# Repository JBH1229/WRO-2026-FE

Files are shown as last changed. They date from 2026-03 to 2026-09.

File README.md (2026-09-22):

# WRO Future Engineers 2026
Our repository for the 2026 World Robot Olympiad: in the category Future Engineers

# Team Costco Hotdog
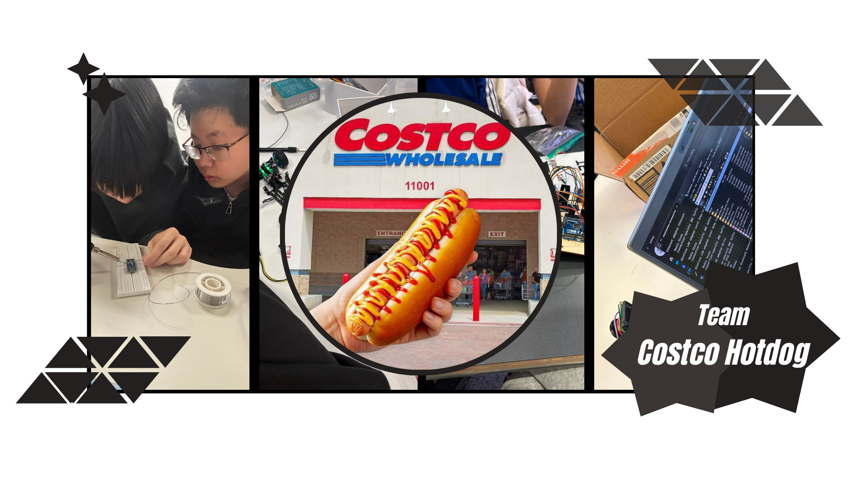
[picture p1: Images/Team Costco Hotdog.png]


## Explorer Robotics





## Table of Contents
* [The Team](#team-members)
* [Engineering Journal](#engineering-journal)
* [The Challenge](#the-future-engineers-challenge)
* [The Robot](#robot)
  * [Overview](#overview) 
  * [First Design](#first-design)
  * [Design Decisions](#design-decisions)
  * [Final Design](#final-design)
* [Prices](#price-of-the-components)
* [Power](#power)
  * [Power budget](#power-budget)
  * [Regulator & BEC Efficiency Losses](#regulator-and-bec-efficiency-losses)
* [Systems](#systems)
  * [Mechanical System](#mechanical-system)
      * [Motor](#motor)
      * [Servo Motor](#servo-motor)
      * [Wheels](#wheels)
  * [Electrical & Sensor System](#electrical-and-sensor-systems)
    * [Regulator](#voltage-regulation)
    * [Circuit Diagram](#circuit-diagram)
* [Software](#software)
* [Testing](#testing)
  * [Performance Videos](#performance-videos)
    * [Open challenge](#open-challenge-video)
    * [Obstacle Challenge](#obstacle-challenge-video)

# Team Members

### Jonathan Huang
**Age:** 15

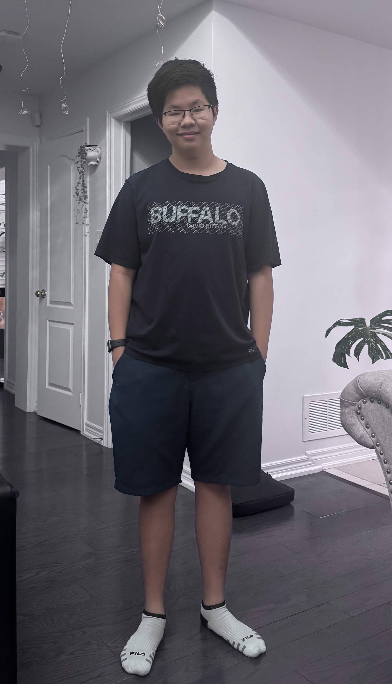
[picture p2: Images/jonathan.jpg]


**Introduction:**
Hi, my name is Jonathan and I'm from Canada, this is my fifth WRO season. I am interested in airplanes, and enjoy learning about how they work in my free time. Besides that, I enjoy playing video games with my friends. I am currently attending Notre Dame CSS.

### Walter Wu
**Age:** 15

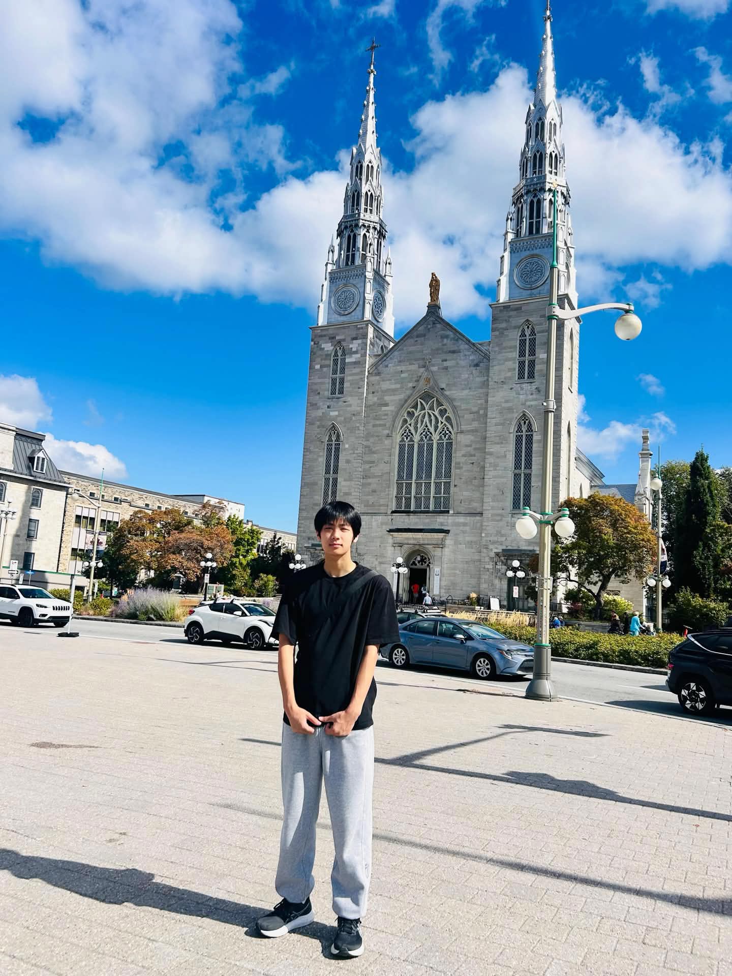
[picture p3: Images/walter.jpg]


**Introduction:**
Hi, my name is Walter and I'm also from Canada, this is my third WRO season;  I have many interests, such as sports like volleyball, and hobbies ranging from drawing and video games to cooking. I am currently attending All Saints CSS and am enrolled in their Arts & Media Program.

# Our Coach
<table>
  <tr>
    <td width="50%" style="text-align: left;">
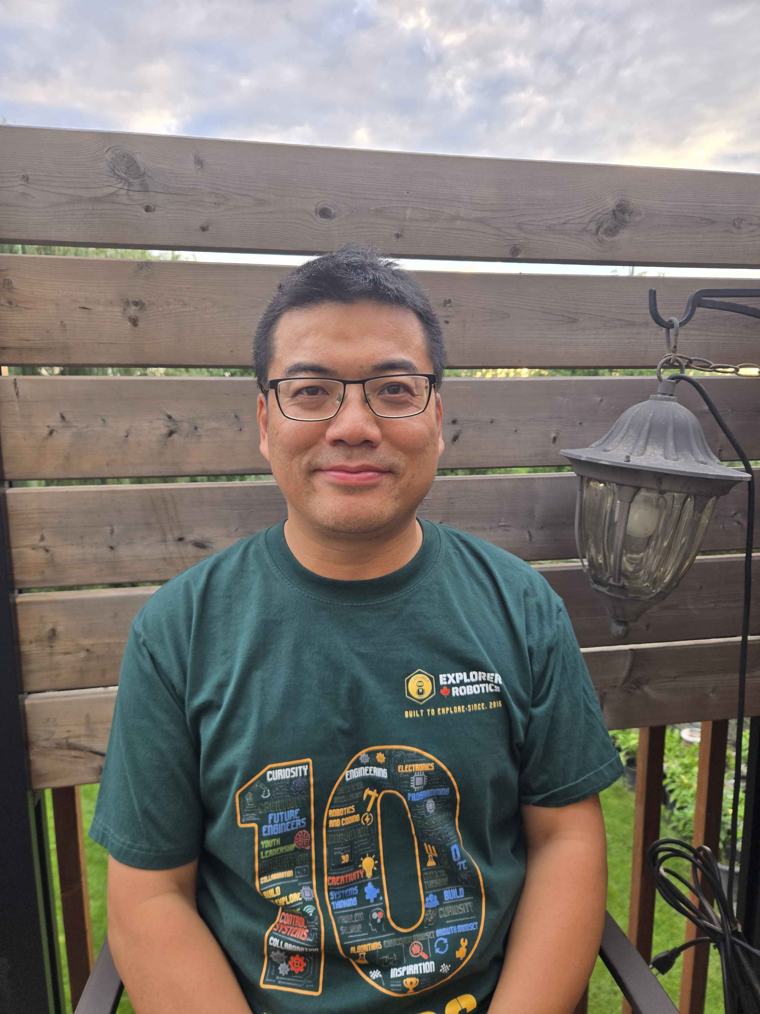
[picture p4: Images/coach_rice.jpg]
       
    </td>
    <td width="50%" style="text-align: left; vertical-align: top;">
      <h3>Accolades:</h3>
      <ul>
        <li>Head coach of Robotics Competitions including FLL (First LEGO League) Tournament and WRO (World Robotics Olympiad). Led teams in winning multiple national, international robotics and programming awards.</li>
        <li>Over 20 years of IT industry experience as software engineer working internationally.</li>
        <li>MSc in Electrical & Computer Engineering from University of Alberta.</li>
        <li>BSc in Mathematics from Peking University.</li>
      </ul>
    </td>
  </tr>
</table>

# Engineering Journal
Here is the link to our [Engineering Journal google document](https://docs.google.com/document/d/1yOxLSaLgVKeupWdl-JZPw-9g1dGKT5EjSAjHi6xOg-0/edit?tab=t.0)

# The Future Engineers Challenge
### Open Challenge

The **Open Challenge** tests our robot's ability to drive autonomously around the track. The robot must complete three laps while adapting to different track layouts, starting positions, and driving directions. The goal is to create a fast and reliable self-driving vehicle that can navigate the track and stop whenever needed without human control.

### Obstacle Challenge

The **Obstacle Challenge** adds red and green traffic signs to the track as well as a parking area. Teams have an option to start and end within the parking area to accumulate more points. While completing three laps, the robot must identify the traffic signs and choose the correct side of the lane to pass on. After finishing the laps, the robot will optionally find the parking area and successfully parallel park.
### Documentation

The **Documentation** focuses on explaining how our robot was designed and developed. Our GitHub repository includes information about the robot's hardware, software, sensors, power system, and driving strategies. It also contains photos, videos, source code, and updates showing our engineering process and improvements throughout the project.

Learn more about the challenges WRO has to offer and the rules accordingly [here](https://wro-association.org/competition/2026-season/) and [here](https://wro-association.org/competition/2026-season/)

# Robot
## Overview

| Dimension | Measurement |
|---|---|
| Length | 21 cm |
| Width | 10 cm |
| Height | 24.5 cm |
| Wheelbase | 10.2 cm |
| Ground Clearance | 3mm |
| Weight | 567g |

## Drive Configuration

The robot uses a **RWD** drivetrain powered by a **Furitek Micro Komodo 1212 brushless motor** and controlled by a **Furitek Lizard Pro ESC**.

### Drive Components

| Component | Specification |
|---|---|
| Motor | Furitek Micro Komodo 1212 |
| Motor Type | Brushless DC |
| ESC | Furitek Lizard Pro |
| Drive Type | RWD |
| Driven Wheels | 1/28 RC drift car wheels |

The motor receives speed commands from the control system through the ESC which decodes PWM messages from the Pi. The drivetrain converts the motor's rotation into forward and reverse movement.

## Steering Configuration

The robot uses **servo-based steering** to control its direction.

### Steering Components

| Component | Specification |
|---|---|
| Steering Servo | HiTec HS-5055MG Micro Servo |
| Control Signal | PWM |
| Maximum Steering Angle | 45° |
| Steering Type | Ball joint |

The steering servo is connected to the front steering mechanism through a mechanical linkage connecting first to a ball joint to drive the steering system.. The controller adjusts the servo position using PWM signals to change the robot's steering angle.

## Main Components

| Component | Purpose |
|---|---|
| Raspberry Pi 5 | Main computer and processing |
| Arduino Nano | Low level commands and processing IMU data |
| Furitek Micro Komodo 1212 | Drives the robot |
| Furitek Lizard Pro ESC | Controls the drive motor |
| Steering Servo | Controls steering |
| D500 LiDAR | Distance measurement |
| Raspberry Pi Camera | Vision and object detection |
| 5 V Regulator | Powers 5 V electronics |
| 11.1 V LiPo Battery | Main power source |
| BMI270 IMU | Used for its gyro sensor |

## Sensors

The robot uses multiple sensors to perceive its surroundings and determine its position on the course.

| Sensor | Purpose | 
|---|---|
| Raspberry Pi Camera | Detects and identifies objects/colours |
| D500 LiDAR | Measures distance to surrounding objects/walls |
| IMU | The gyro sensor inside calculates the robot's heading |

Sensor data is processed by the robot's control software and used to make driving and steering decisions.

### PHOTO OF SENSORS ON ROBOT ###
| *Pi Camera* | *2D LiDAR* | *IMU* |
| :--: | :--: | :--: |
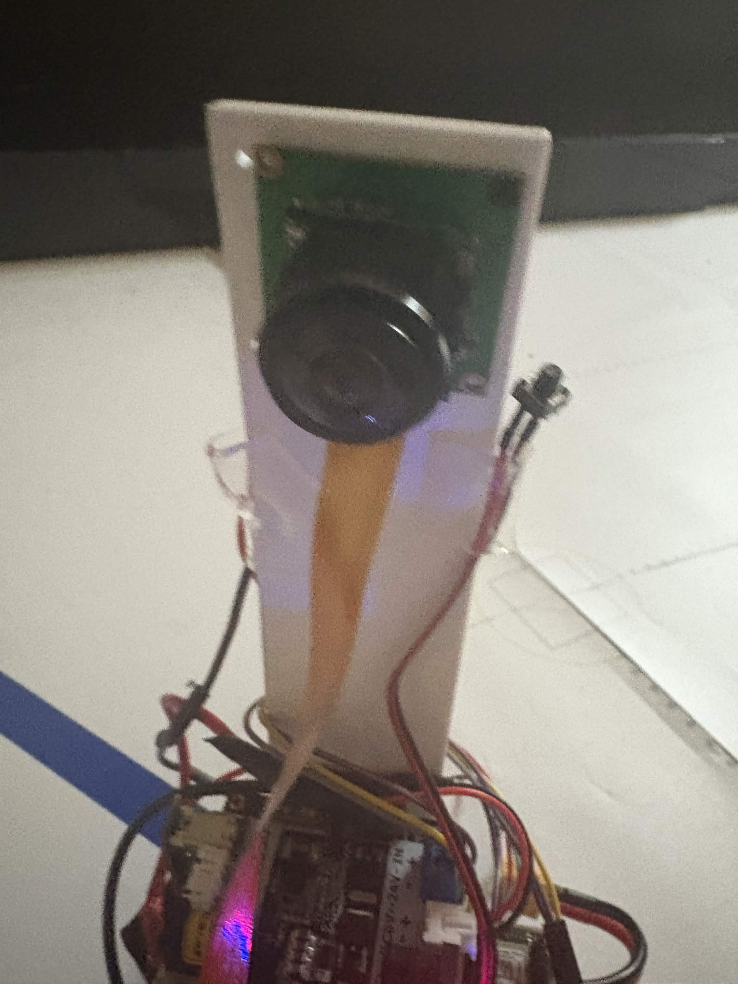
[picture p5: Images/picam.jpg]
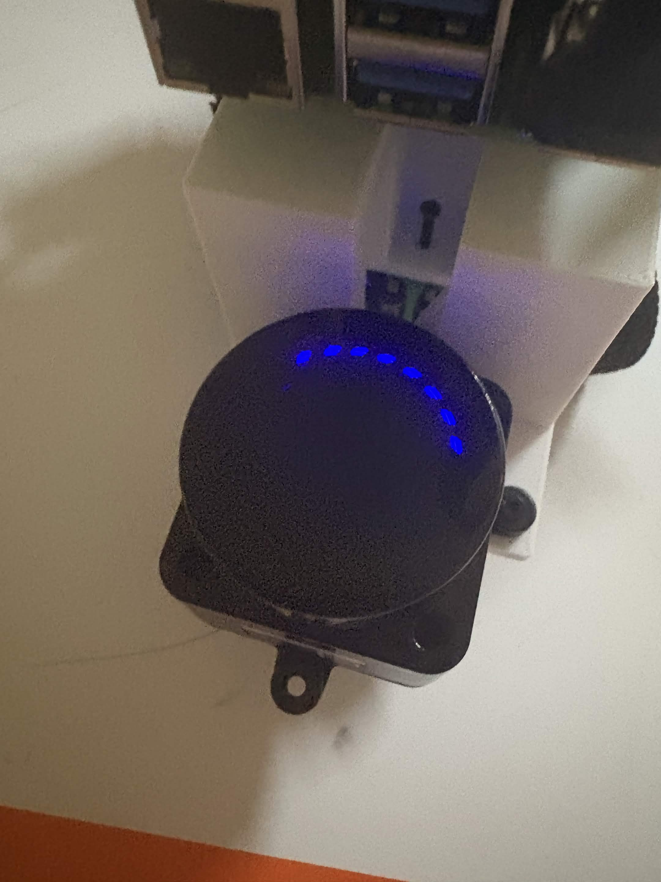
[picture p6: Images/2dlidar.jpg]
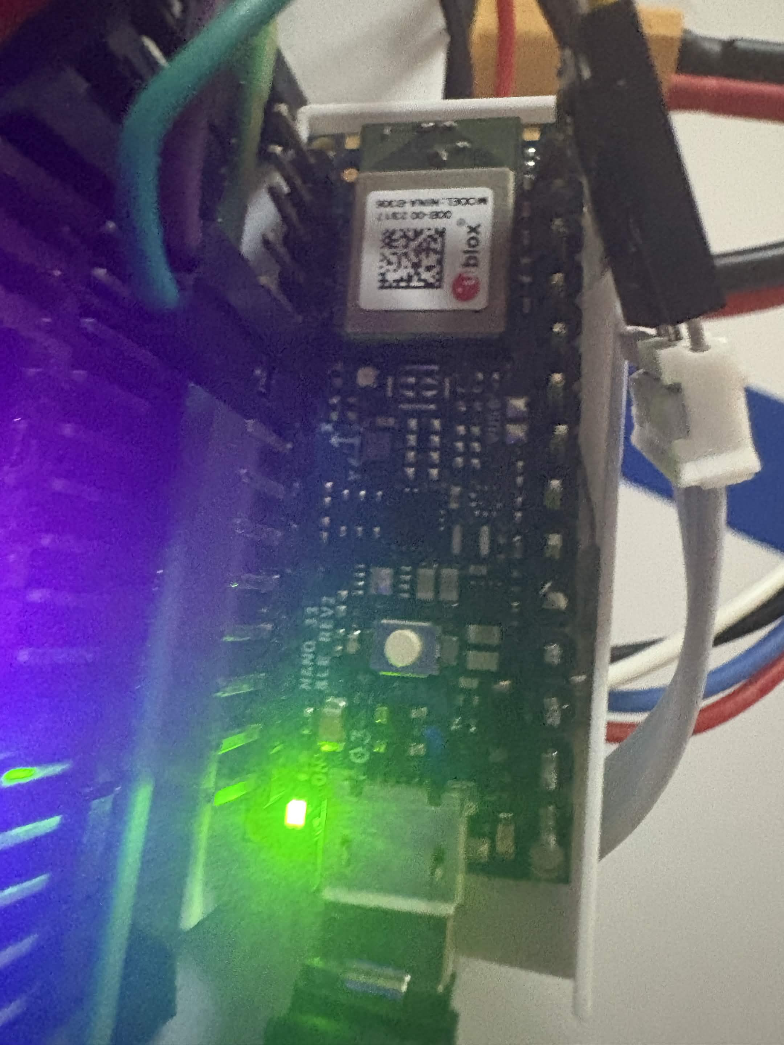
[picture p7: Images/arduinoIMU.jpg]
|  |  |  |

## Computer / Controller

The main computer is a **Raspberry Pi 5**, which processes sensor data and runs the robot's control software.

An **Arduino Nano** is used for low-level control of the robot's steering servo and motor ESC, as well as processing IMU data to track the robot's heading.

### Computer/Controller Components

| Component | Function |
|---|---|
| Raspberry Pi 5 | Main processing, computer vision, navigation and decision-making |
| Arduino Nano | Low level commands and IMU interpretation |
| Motor ESC | Motor control |
| Steering Servo | Steering control |

The Raspberry Pi receives information from the sensors, processes the data, and sends control commands to the Arduino, which then controls the drive and steering systems.

## Battery

The robot is powered by an **11.1 V 2200 mAh 3-cell LiPo battery**.

| Specification | Value |
|---|---|
| Battery Type | LiPo |
| Cells | 3S |
| Nominal Voltage | 11.1 V |
| Capacity | 2200 mAh |
| Average Current | ~3.5 A |
| Peak Current | ~15 A |
| Average Power | ~38 W |
| Estimated Runtime | 40–60 minutes |

The battery directly powers the drive system and provides power to the electronics through the appropriate voltage regulation.

## How It Works

The robot operates using a combination of **computer vision, LiDAR distance sensing, and autonomous control**.

The **Raspberry Pi 5** collects information from the camera and LiDAR and processes this data using the robot's control software. The camera is used to identify relevant objects and course features, while the LiDAR provides distance measurements to help the robot understand its surroundings.

Based on the sensor data, the software determines the appropriate **steering angle and driving speed**. Steering commands are sent to the steering servo, while drive commands are sent to the motor through the **Furitek Lizard Pro ESC**.

The robot continuously repeats this process:

**Sense → Process → Decide → Drive/Steer → Sense**

## First design
These are a couple pictures of the first variation of our robot
| *Side* | *Camera Detached* |
| :--: | :--: |
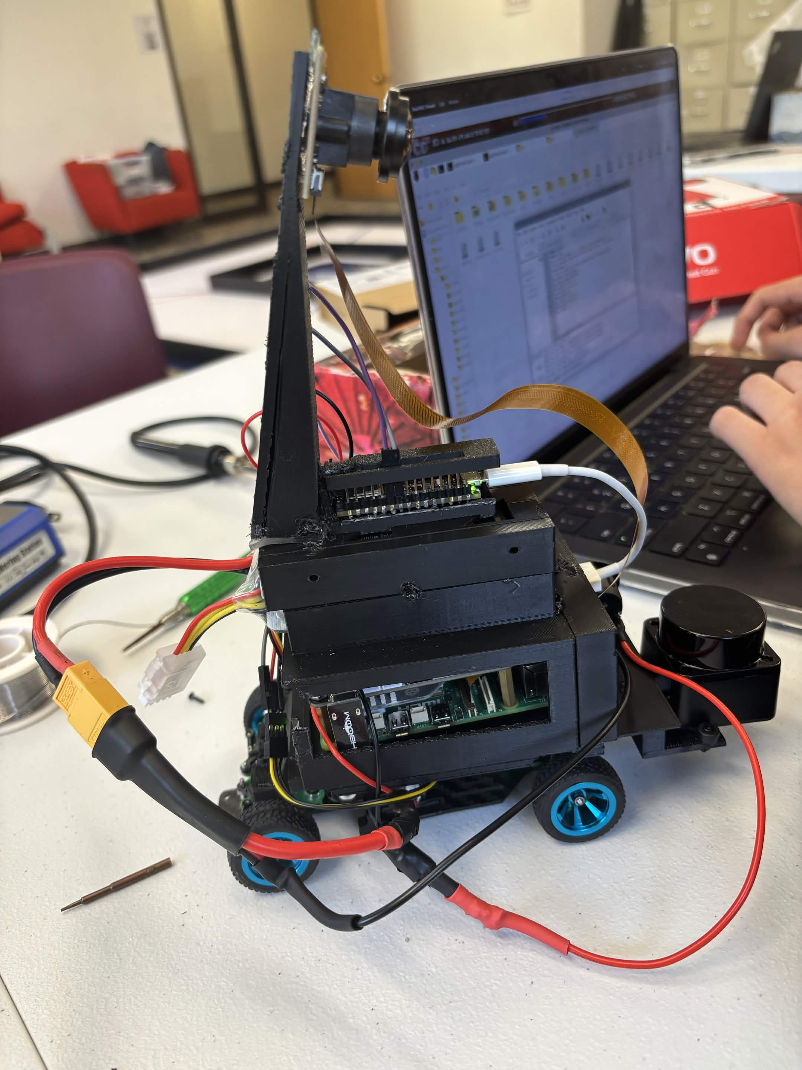
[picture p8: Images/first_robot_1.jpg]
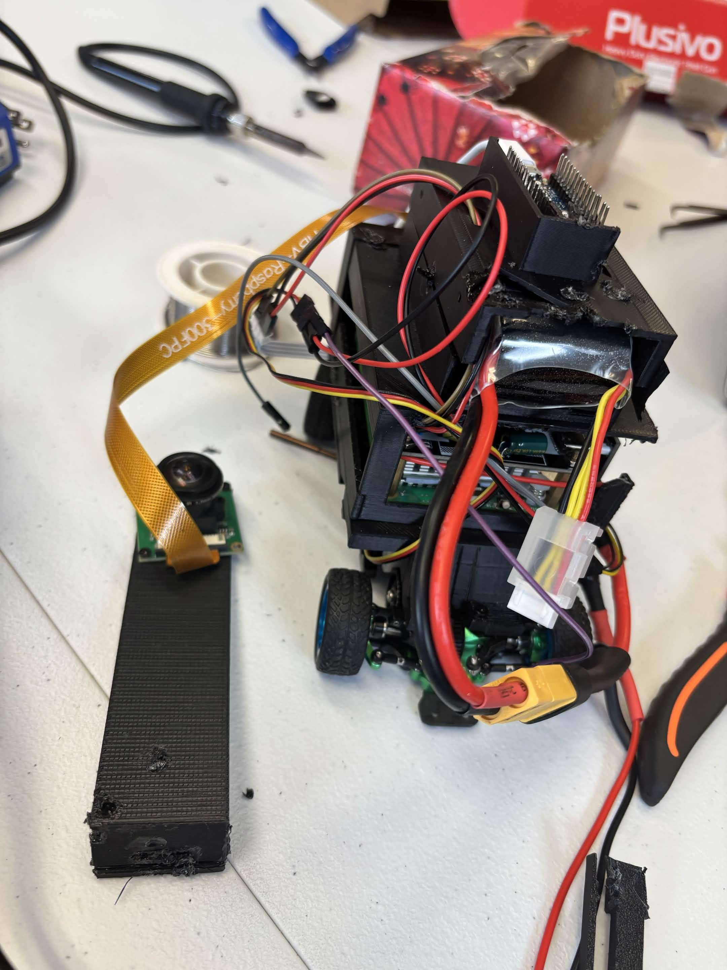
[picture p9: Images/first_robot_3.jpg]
|  |  | 

### Early CAD designs
The following are photos of early iterations for the chassis and camera stand
| *Camera Stand* | *Chassis* |
| :--: | :--: |
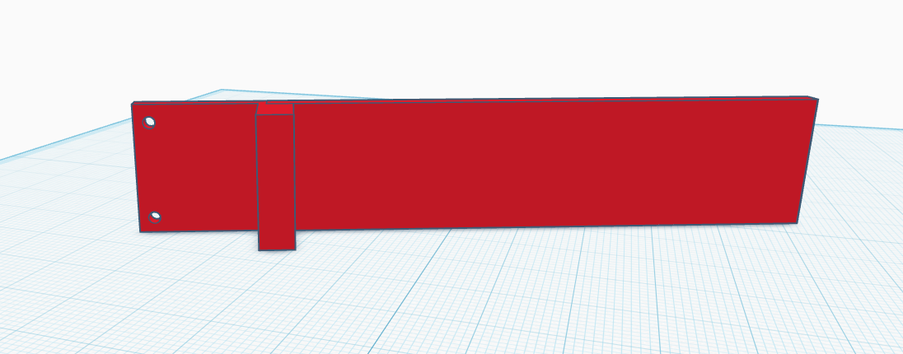
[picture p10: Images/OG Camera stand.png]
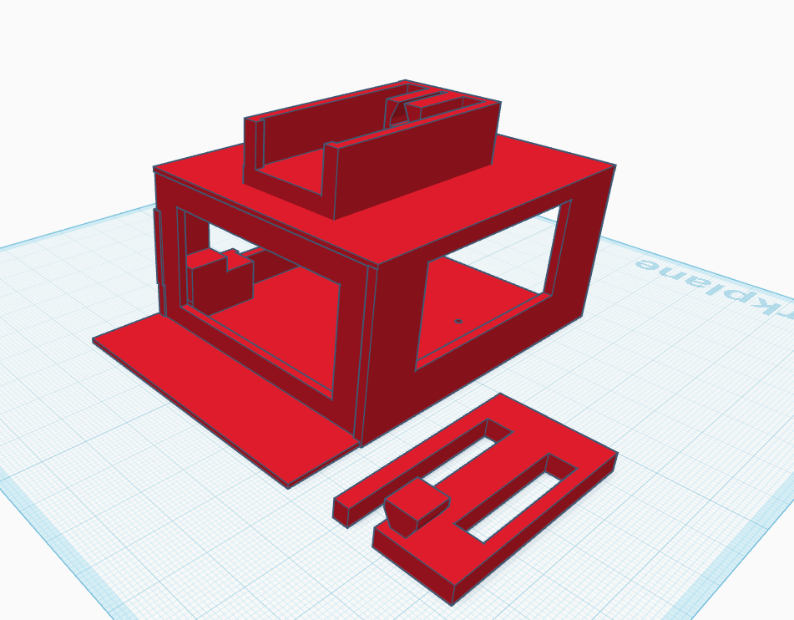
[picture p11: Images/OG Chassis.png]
|  |  | 

## Design Decisions
A lot of the design decisions were based on the information and research done on previous robots from both team members and our club.
| Challenge | Decision | Reasoning |
|---|---|---|
| Drive system | Furitek Micro Komodo 1212 BLDC motor with a Furitek Lizard Pro ESC | Provides enough torque and speed for the robot while remaining compact and efficient. The brushless motor also provides reliable and precise control. |
| Size | 1/24 - 1/28 scale | A compact design makes the robot easier to maneuver, turn, and navigate through tight sections of the course while staying within the competition size limits. |
| Battery | 11.1 V 2200 mAh 3-cell LiPo battery | Provides enough voltage for the drive system and sufficient capacity for the robot to operate throughout a run while keeping the overall weight low. |
| Controller | Raspberry Pi 5 with an Arduino Nano | The Raspberry Pi 5 handles sensor processing, decision-making, and higher-level control, while the Arduino Nano handles real-time communication with the drive and steering systems. |
| Sensors | D500 LiDAR, Raspberry Pi Camera, and BMI270/BMM150 IMU | LiDAR provides distance measurements for navigation and wall detection, the camera provides visual information, and the IMU provides orientation and motion data for more accurate movement and turning. |

A **more detailed breakdown** of our decisions can be found in our [Engineering Journal](https://docs.google.com/document/d/1yOxLSaLgVKeupWdl-JZPw-9g1dGKT5EjSAjHi6xOg-0/edit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)

## Wheelbase
The distance for our wheelbase was chosen to be shorter to help with agility, nmainly so our robot could take shaper and more concise turns if needed to. This especially helps with the obstacle challenge and proved to be beneficial during the suprise rule for nationals, where we had to navigate around an extra, yellow coloured, pillar. When you look at real life examples of cars with long wheelbases, such as F1 cars, it is noted that F1 cars also have a trouble with turning. One reason behind this is that having a longer wheelbase directly increases the turn radius of your car. A larger turn radius means wider turns and completely contrasts the goal for our autonomous robots.

Learn about our robots turn radius in our engineering journal on page 12 [Engineering Journal](https://docs.google.com/document/d/1yOxLSaLgVKeupWdl-JZPw-9g1dGKT5EjSAjHi6xOg-0/edit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)

## Final Design
Here are photos of our final design|

| *Front* | *Back* |
| :--: | :--: |
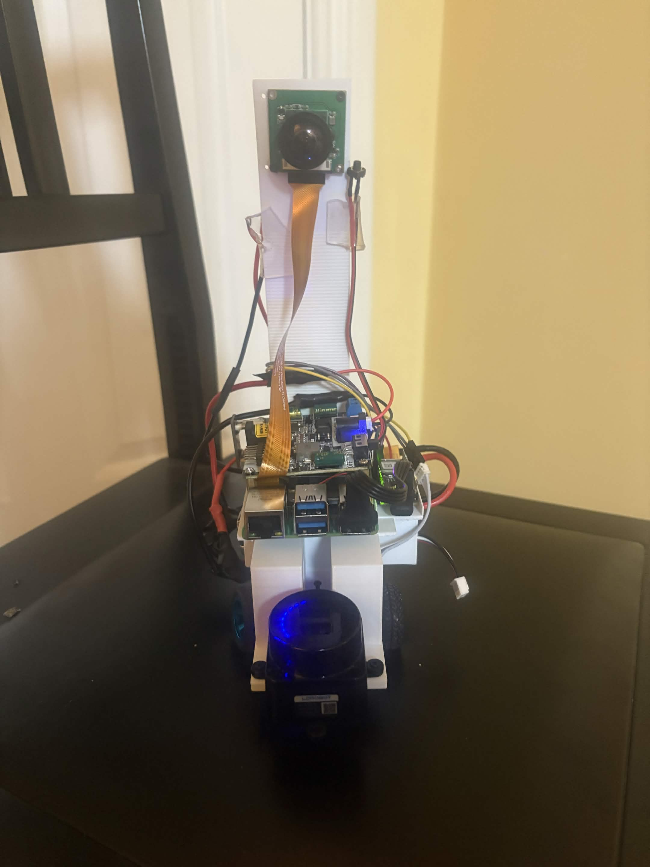
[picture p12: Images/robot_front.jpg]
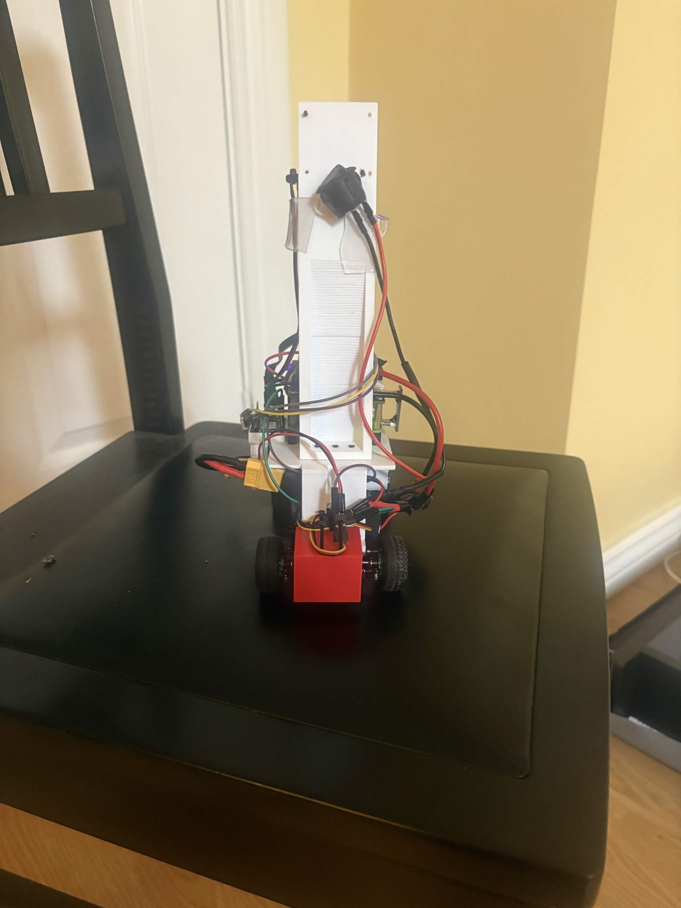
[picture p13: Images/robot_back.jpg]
|  |  | 
| *Left* | *Right* |
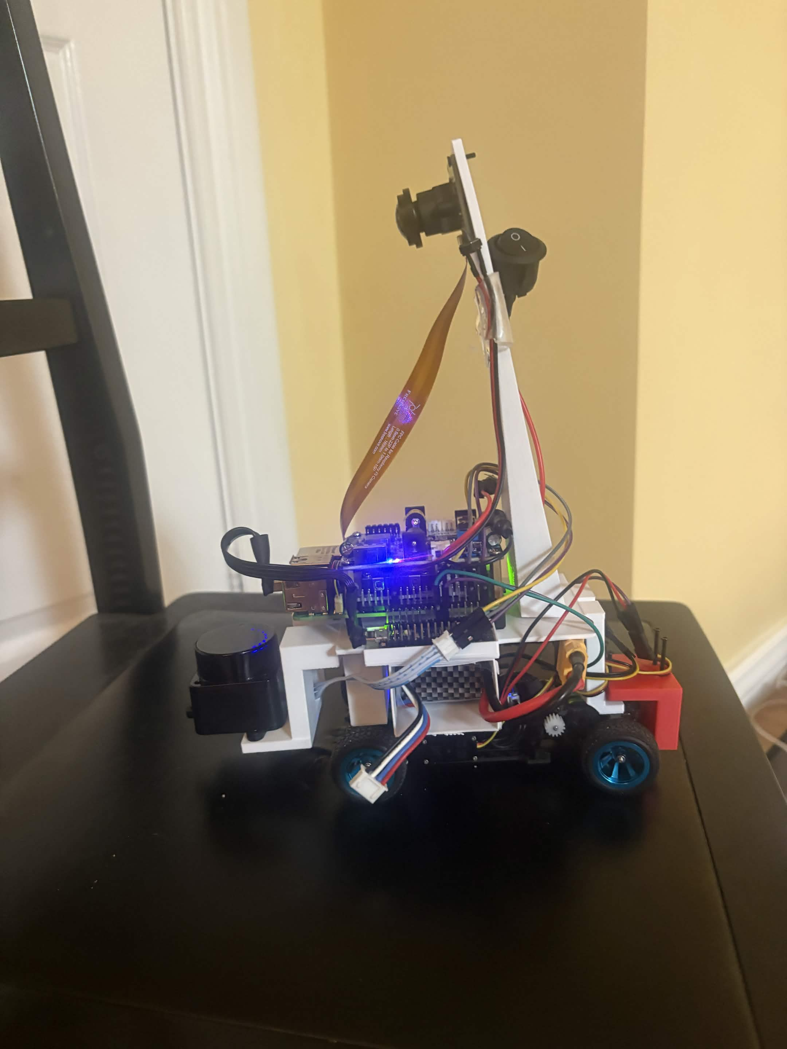
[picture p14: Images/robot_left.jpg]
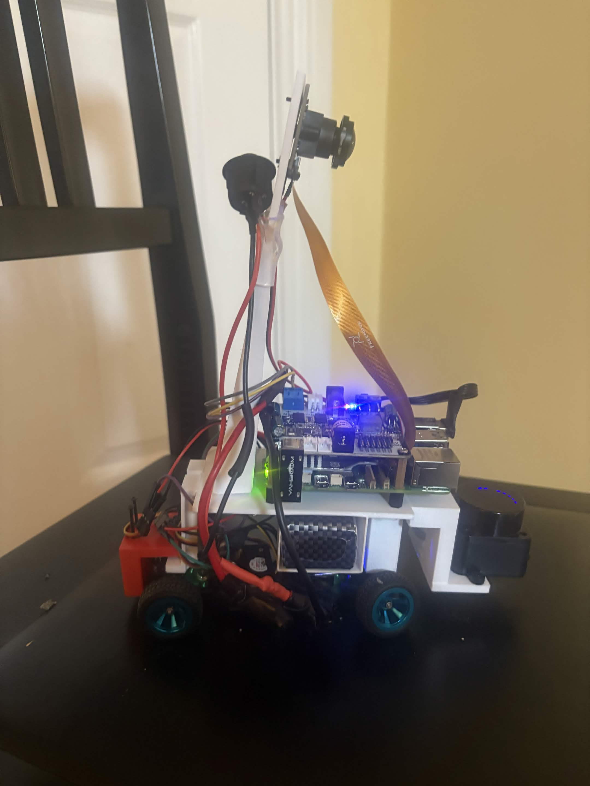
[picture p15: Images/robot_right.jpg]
|  |  | 
| *Top* | *Bottom* |
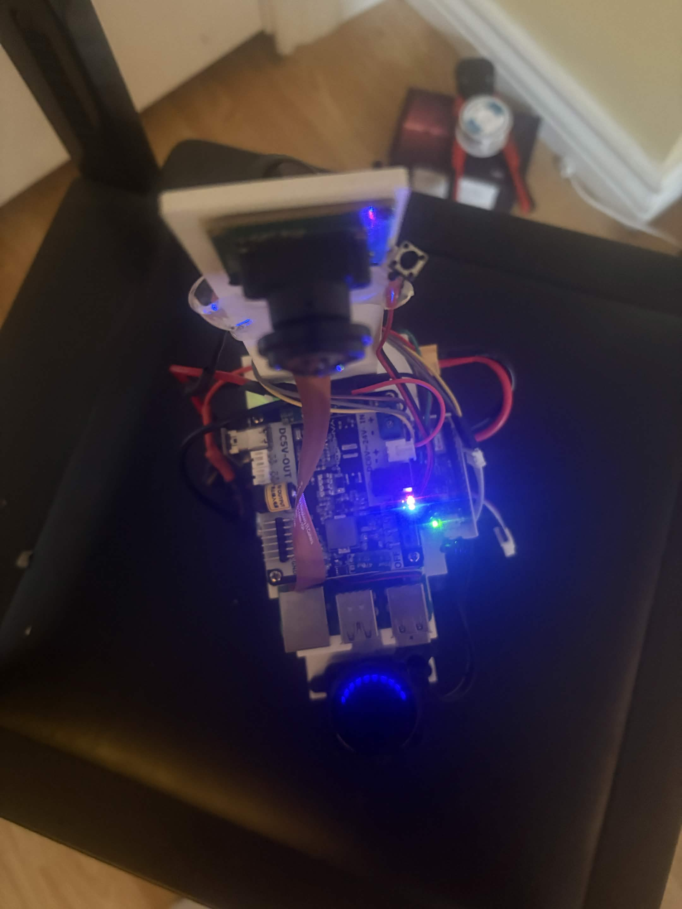
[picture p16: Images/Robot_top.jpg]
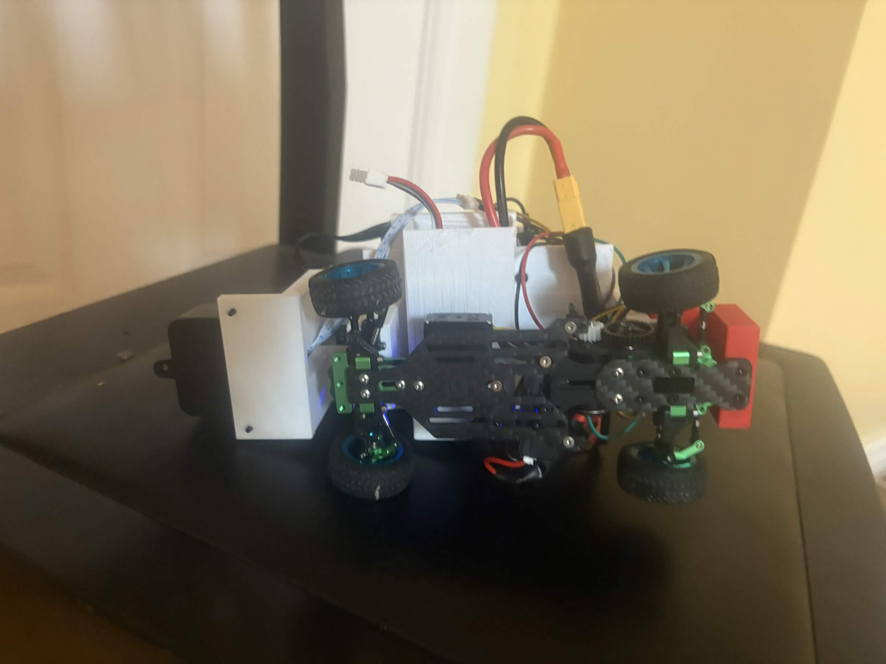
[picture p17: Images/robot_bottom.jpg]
|  |  | 

Click [here](Electrical/README.md#why-we-changed-the-robot) to see the main differences between the first and final renditions of our robot

# Price of the Components
| Component  | Cost |
| --- | --- |
| [BLDC Motor](https://furitek.com/products/furitek-micro-komodo-1212-3456kv-brushless-motor-with-15t-steel-pinion-for-fury-wagon-fx118)  | $34.99 | 
| [Furitek Lizard Pro ESC](https://furitek.com/products/combo-of-furitek-lizard-pro-30a-50a-brushed-brushless-esc-for-axial-scx24-with-bluetooth) | $79.99 | [here](https://furitek.com/products/combo-of-furitek-lizard-pro-30a-50a-brushed-brushless-esc-for-axial-scx24-with-bluetooth) |
| [Servo Motor](https://hitecrcd.com/hs-5055mg-economy-metal-gear-feather-servo/)  | $29.99  |
| [Camera](https://www.amazon.ca/dp/B0D324RKRZ?ref=ppx_yo2ov_dt_b_fed_asin_title)  | $43.30 |
| [Raspberry Pi 5 + MicroSD card + Additions](https://www.pishop.ca/product/raspberry-pi-5-8gb/?src=raspberrypi)  | $312.80  |
| [Arduino Nano](https://store-usa.arduino.cc/products/nano-33-ble-sense-rev2-with-headers) | $39.70  |
| [Chassis](https://www.aliexpress.com/item/1005010095696996.html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)  | $140.38  |
| [3-cell Battery](https://www.amazon.ca/Zeee-Battery-Connector-Airplane-Helicopter/dp/B0D5LKXHBK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)  | $46.99  |
| [LiDAR sensor](https://www.aliexpress.com/item/1005003012681021.html?spm=a2g0o.order_list.order_list_main.31.67dd18029q37Y0)  | $81.14  |
| [Regulator](https://ca.robotshop.com/products/yahboom-power-supply-expansion-board-raspberry-pi-5) | $17.54 |
| [Nano tape](https://www.amazon.ca/Ohayooz-Removable-Adhesive-Washable-Waterproof/dp/B0DJX3J7V6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) | $9.97 |
| [3d-prints](3d-prints) | $24.99 |
| [Screw Set](https://www.aliexpress.com/item/1005002438190831.html) | $22.65 |
| [Wheels](https://www.amazon.ca/AllinRC-Pre-glued-Compatible-WLtoys-Racing/dp/B0B4DH61L9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) | $26.87 |
| Total Price Before Tax | $911.3  |
| Total Price | $1 029.77  |

***The additions to the RASPI 5 include but are not limited to USB-C PD Power Supply, Raspberry Pi Active Cooler, and a Micro-HDMI to HDMI cable***

# Power

## Power Budget

| Component | Voltage (V) | Current (A) | Power (W) | Notes / Rail |
| :--- | :--- | :--- | :--- | :--- |
| Raspberry Pi 5 | 5.0 | 1.80 | 9.00 | 5V Regulated Rail |
| Pi Camera | 5.0 | 0.25 | 1.25 | 5V Regulated Rail |
| Arduino Nano | 5.0 | 0.03 | 0.15 | 5V Regulated Rail |
| D500 LiDAR | 5.0 | 0.20 | 1.00 | 5V Regulated Rail |
| HiTec HS-5055MG Servo | 6.0 | 0.15 | 0.90 | 6V BEC Rail |
| Furitek ESC Electronics | 6.0 | 0.05 | 0.30 | 6V BEC Rail |
| Furitek Micro Komodo 1212 Motor | 11.1 | 2.00 | 22.20 | 11.1V Direct Rail |
| **Total Device Power** | | | **34.80 W** | |

---

## Battery Specifications

| Parameter | Value |
| :--- | :--- |
| **Brand / Model** | Zeee 3S LiPo |
| **Battery Type** | LiPo |
| **Cell Count** | 3S |
| **Nominal Voltage** | 11.1 V |
| **Capacity** | 2200 mAh (2.2 Ah) |
| **Energy** | 24.42 Wh ($11.1\text{ V} \times 2.2\text{ Ah}$) |
| **Discharge Rating** | 50C |
| **Maximum Continuous Current** | 110 A ($2.2\text{ Ah} \times 50\text{C}$) |

---

## Regulator and BEC Efficiency Losses

* **5V Regulated Rail (Yahboom Power Board @ 92% Efficiency):**

The Yahboom Raspberry Pi 5 power board operates at approximately **92% efficiency**. Supplying the 11.4 W 5V rail requires approximately 12.39 W from the battery, resulting in about 0.99 W of conversion losses.
  * 5V rail power demand: `11.40 W`
  * Battery-side power required: $\frac{11.40\text{ W}}{0.92} = 12.39\text{ W}$
  * 5V conversion losses: `0.99 W`

* **6V BEC Rail (Furitek Lizard Pro Internal BEC @ 85% Efficiency):**

A BEC (Battery Eliminator Circuit) loses efficiency primarily because converting a higher voltage (like 11.1V from a 3S LiPo) down to a lower voltage (like 6.0V for a servo) generates heat and requires power to run its own circuit.
  * 6V rail power demand: `1.20 W` ($0.90\text{ W} + 0.30\text{ W}$)
  * Battery-side power required: $\frac{1.20\text{ W}}{0.85} = 1.41\text{ W}$
  * 6V conversion losses: `0.21 W`

---

## Total Battery Power Consumption

| Quantity | Value |
| :--- | :--- |
| **Total Device Power** | 34.80 W |
| **5V Regulator Losses** | 0.99 W |
| **6V BEC Conversion Losses** | 0.21 W |
| **Total Battery Power Draw** | **36.00 W** |

---

## Runtime Calculation

$$\text{Runtime} = \frac{\text{Battery Energy}}{\text{Total Power}} = \frac{24.42\text{ Wh}}{36.00\text{ W}} \approx 0.678\text{ hours}$$

$$0.678\text{ h} \times 60 \approx 40.7\text{ minutes}$$

---

## Estimated Runtime

| Operating Condition | Runtime |
| :--- | :--- |
| Full-speed continuous driving | ~40 min |
| A normal WRO run (mixed acceleration) | ~50–60 min |
| Idle robot with vision processing | ~90 min |

---

## Battery Current Draw & Capability Check

### Average Battery Current
$$I_{\text{avg}} = \frac{P_{\text{total}}}{V_{\text{nominal}}} = \frac{36.00\text{ W}}{11.1\text{ V}} \approx 3.24\text{ A}$$

### Peak & Discharge Safety Margin
* **Zeee 3S Battery Continuous Max:** `110 A` ($2.2\text{ Ah} \times 50\text{C}$)
* **Estimated Peak Demand:** `12–16 A` (Motor stall + high servo load)
* **Safety Margin Factor:** $\frac{110\text{ A}}{16\text{ A}} \approx 6.87\times$

The Zeee LiPo battery can comfortably supply peak loads well within thermal safety limits.

---

## Power Rail Distribution

### 11.1V Direct Battery Rail
* **Connected Components:** Furitek Lizard Pro ESC & Furitek Micro Komodo 1212 Motor
* **Average Current:** `2.00 A`
* **Peak Current:** `8.00–12.00 A`
* **Average Power:** `22.20 W`

### 6V BEC Rail (Integrated ESC BEC @ 85% Efficiency)
* **Connected Components:** HiTec HS-5055MG Servo & ESC Electronics
* **Average Current:** $0.15\text{ A} + 0.05\text{ A} = 0.20\text{ A}$
* **Peak Current:** $0.70\text{ A} + 0.10\text{ A} \approx 0.80\text{ A}$
* **Average Power:** $6.0\text{ V} \times 0.20\text{ A} = 1.20\text{ W}$

### 5V Regulated Rail (Yahboom Power Board @ 92% Efficiency)
* **Connected Components:** Raspberry Pi 5, Camera, D500 LiDAR, Arduino Nano
* **Average Current:** $1.80\text{ A} + 0.25\text{ A} + 0.20\text{ A} + 0.03\text{ A} = 2.28\text{ A}$
* **Power Delivered to Electronics:** $5.0\text{ V} \times 2.28\text{ A} = 11.40\text{ W}$
* **Battery Power Consumed (with efficiency loss):** $\frac{11.40\text{ W}}{0.92} = 12.39\text{ W}$
* **Battery Current Consumed:** $\frac{12.39\text{ W}}{11.1\text{ V}} \approx 1.12\text{ A}$
* **Recommended Regulator Rating:** Minimum `5V @ 4A` continuous output.

## Overview
The robot’s power source is an 11.1V, 2200mAh, 3-cell LiPo battery. The drive unit includes a Furitek Micro Komodo BLDC motor and Furitek Lizard Pro controller. A 5V power supply is used for powering the Raspberry Pi 5, LiDAR sensor, camera, and Arduino Nano. The average total battery power consumption of the robot is 36.0 W, which includes the Raspberry Pi 5 (9.0 W), camera (1.25 W), LiDAR sensor (1.0 W), steering servo (0.9 W), Arduino Nano (0.15 W), Furitek electronics and brushless drive system (22.5 W), and conversion losses (1.20 W). The average current consumption from the battery is approximately 3.24 A, which provides an estimated continuous full-speed runtime of about 40 minutes (and 50–60 minutes under typical WRO run conditions). The estimated maximum peak current demand during acceleration or stall is 12–16 A.

# Systems
## Mechanical System

The mechanical system forms the basis for the framework, motion, and steering of the robot. This is made up of the chassis, drive motor, servo motor, wheels, and steering. Each part has been chosen and placed precisely to ensure stability, maneuverability, durability, and space.

### Chassis

The chassis acts as the main structure of the robot and houses the mounting points for the drive systems, steering systems, battery, electronics, and sensors. The chassis design is done in such a way that the robot remains small yet has room for all the parts while remaining lightweight. The mounting of the components ensures that they remain stable.

**Chassis Specifications:**

| Specification | Value |
|---|---|
| Material | Plastic & Carbon-Fiber |
| Length | 21cm |
| Width | 10cm |
| Height | 22.5cm |

### Motor

The robot incorporates a **Furitek Micro Komodo 1212 brushless DC motor** for its drive system. The motor is controlled through the use of a **Furitek Lizard Pro ESC**, which controls the amount of energy being supplied to the motor. The motor supplies the energy needed to rotate the wheels and was chosen due to its speed and torque.

**Motor Specifications:**

| Specification | Value |
|---|---|
| Motor | Furitek Micro Komodo 1212 |
| Type | Brushless DC (BLDC) |
| Operating Voltage | 11.1 V |
| Average Current | 2.0 A |
| Average Power | 22.2 W |
| ESC | Furitek Lizard Pro |

### Servo Motor

The steering of the robot is controlled by the servo motor. The servo motor will receive the signals from the Arduino for the steering and turn to the appropriate position. This movement is transmitted through the steering linkage to adjust the front wheels' angles. The servo was chosen because it provided the necessary torque and fit in the restricted space of the robot.

**Servo Specifications:**

| Specification | Value |
|---|---|
| Servo Model | [HiTec HS-5055MG Micro Servo] |
| Operating Voltage | [4.8-6.0V] |
| Torque | [18.05-22.2 oz-in] |
| Steering Range | [~80°] |
| Average Power | 3.0 W |

### Wheels

Wheels are used in the design to give traction and stability during movement. The wheels are mechanically linked with the drivetrain system in order to transmit power from the drive motor to the wheels. The size and tread pattern of the wheels have been chosen keeping in mind the traction and stability requirements.

**Wheel Specifications:**

| Specification | Value |
|---|---|
| Number of Wheels | 4 |
| Wheel Diameter | ~30mm |
| Wheel Width | 12mm |
| Material | Aluminum Alloy |
| Tread Type | Slick/Smooth Tread |

### Steering

We use a RWD system for the robot which is powered by the servo motor. The servo causes the steering linkage to change the angle at which the front wheels point, and hence steer the robot. The steering system has been engineered to have accurate steering control and minimal movement or sloppiness of the linkage.

**Steering Configuration:**

| Specification | Value |
|---|---|
| Steering Type | Power-assisted |
| Steering Wheels | Front wheels |
| Steering Actuator | Servo motor |
| Steering Mechanism | Ball joint |
| Maximum Steering Angle | 45° |

## Electrical and Sensor Systems

The electrical and sensor systems are responsible for providing power, sensing, and communication between different parts of the robot. The system includes a 11.1 V lithium polymer battery, the Raspberry Pi 5, the Arduino Nano, a Raspi camera, the LiDAR, and the electronics related to driving and steering of the robot. All these parts interact with each other to sense the environment for the robot.

*You can refer back to our [Power section](#power) for the detailed specifications on the battery and power budget.*

### Voltage Regulation

The battery provides a nominal voltage of **11.1 V**, while several components require lower operating voltages. Voltage regulators are therefore used to provide stable power to the electronics.

A regulated **5 V supply** powers the Raspberry Pi 5, Pi Camera, Arduino Nano, and D500 LiDAR. The steering servo and ESC electronics operate from an appropriate regulated supply. Voltage regulation protects the electronics from unsuitable voltage levels and helps maintain stable operation throughout the robot's run.

**Voltage Distribution:**

| Component | Required Voltage | Power Source |
|---|---:|---|
| Raspberry Pi 5 | 5.0 V | Voltage Regulator |
| Pi Camera | 5.0 V | 5 V Supply |
| Arduino Nano | 5.0 V | 5 V Supply |
| D500 LiDAR | 5.0 V | 5 V Supply |
| Servo Motor | 6.0 V | Regulated Supply |
| ESC | 6.0 V | Regulated Supply |
| Drive Motor | 11.1 V | Battery |

### Circuit Diagram 

The electrical system connects the battery, voltage regulators, Raspberry Pi, Arduino, sensors, ESC, servo, and drive motor.

The **Raspberry Pi 5** processes information from the camera and LiDAR and communicates control commands to the Arduino. The Arduino controls the steering servo and communicates with the drive system. The battery provides the main power source, while voltage regulation provides the appropriate voltages for the individual components.

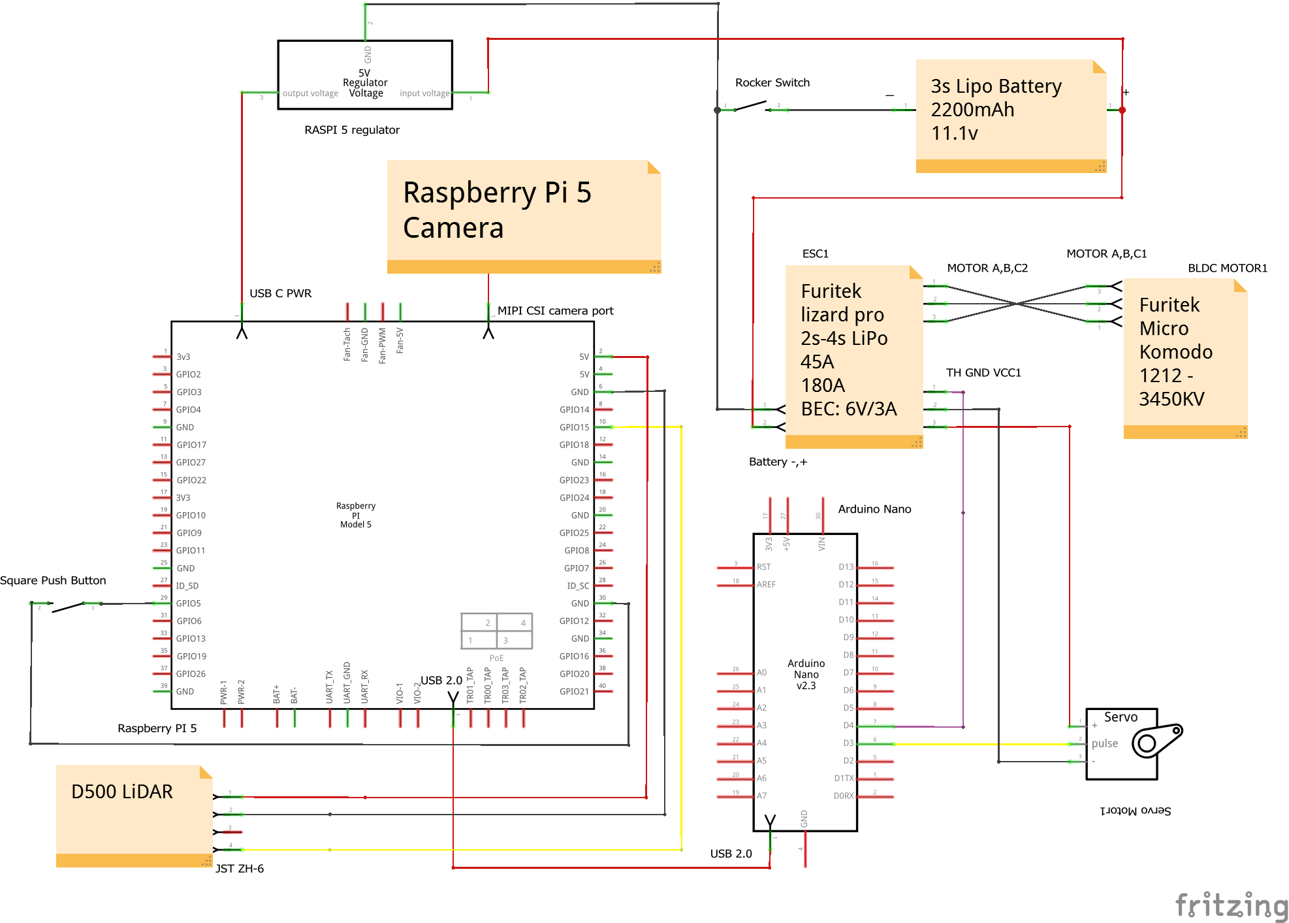
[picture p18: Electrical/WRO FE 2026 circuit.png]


**Electrical System Flow:**

```text
                    11.1 V LiPo Battery
                            |
             +--------------+--------------+
             |                             |
             v                             v
       Voltage Regulators             Lizard Pro ESC
             |                             |
      +------+------+                      v
      |      |      |                Micro Komodo
      |      |      |                    Motor
      v      v      v
 Raspberry Arduino  D500
   Pi 5     Nano   LiDAR
     |
     v
 Pi Camera

Arduino Nano
     |
     +----> Steering Servo
```
## Camera



The robot uses a **Raspberry Pi Camera** which excels in taking images of the surrounding environment during the competition. Images provided by the camera are analyzed by the Raspberry Pi 5, helping the robot recognize various aspects of the course.

The camera is mounted on the Raspberry Pi so that it gives a good picture of the space in front of the robot including the side walls. The images taken by the camera are processed using computer vision algorithms before being used for navigation.

### Camera Specifications

| Specification | Value |
|---|---|
| Camera | Raspberry Pi Camera |
| Interface | 15-pin MIPI CSI |
| Resolution | 1080p @ 30fps / 720p @ 60fps |
| Field of View | 175° |
| Purpose | Computer Vision / Navigation |

## LiDAR



The robot uses a **D500 LiDAR sensor** for parking only. The LiDAR provides distance measurements that allow the Raspberry Pi to determine the robot's position relative to the parking walls and outside walls.

LiDAR data is processed by the Raspberry Pi and used by the navigation system to maintain the desired distance from walls and detect changes in the robot's surroundings.

### LiDAR Specifications

| Specification | Value |
|---|---|
| Sensor | D500 LiDAR |
| Connection | 4-pin JST |
| Operating Voltage | 5.0 V |
| Average Current | 0.20 A |
| Average Power | 1.00 W |
| Primary Purpose | Distance Measurement |

## Sensor Placement

The placement of the camera and LiDAR was designed while keeping in mind not to block anything from the front and sides of their FOV.

The **camera** is positioned to provide a clear lifted forward-facing view of the course. The **LiDAR** is positioned so that it can measure the distance between the robot and surrounding walls or obstacles. The sensors are mounted securely to prevent movement and maintain consistent measurements during operation.

# Software

# Autonomous Robot State Machine Documentation

## 1. ASCII State Machine Diagram

```text
                        +---------------------------------------+
                        |            INITIALIZATION             |
                        | - Init Serial & Cam                   |
                        | - Servo = 66                          |
                        | - Motor = 1500 -> 1622                |
                        +-------------------+-------------------+
                                            |
                                            v
                        +---------------------------------------+
   +------------------->|              WALL_FOLLOW              |<-------------------+
   |                    | - Steering: PD Control                |                    |
   |                    |   (leftArea-rightArea)                |                    |
   |                    | - Speed = 1622                        |                    |
   |                    +----+-----------------------------+----+                    |
   |                         |                             |                         |
   |                         |                             |                         |
[No Pillar for               |                             | [low_left/right         | [Gyro turned
 8 consecutive               | [Active Color]              |  for 5 frames           |  <= GYRO_VAL]
 frames]                     |                             |  AND time_elapsed]      |  OR [Area grew
   |                         v                             v                         |  AND time_ok]
   |            +-------------------------+   +-------------------------+            |
   +------------|      PILLAR_AVOID       |   |       CORNER_TURN       |------------+
                | - Target CX:            |   | - Servo: 41° L / 81° R  |
                |   Red(40)/Grn(600)      |   | - Speed = 1622          |
                | - Steering: P Control   |   | - turn_count ++         |
                +-------------------------+   | - lap_count ++          |
                                              |   (every 4 turns)       |
                                              +------------+------------+
                                                           |
                                                   [turn_count >= 12]
                                                           |
                                                           v
                        +---------------------------------------+
                        |                END_RUN                |
                        | - end_run_counter ++                  |
                        +-------------------+-------------------+
                                            |
                                  [counter >= 100 frames]
                                            |
                                            v
                        +---------------------------------------+
                        |                 STOP                  |
                        | - Servo = 66 (Center)                 |
                        | - Motor = 1500 (Stop)                 |
                        | - Cleanup & Exit                      |
                        +---------------------------------------+
```

---

## 2. State Descriptions
### INITIALIZATION

- **Function**: Initializes the robot's hardware interfaces, including the Arduino serial connection at 115200 baud, LiDAR at 230400 baud, Raspberry Pi Camera, and start button.
- **Operations**:
  - Sets the default servo position to **82°** and motor value to **1500**.
  - Clears the Arduino and LiDAR serial buffers.
  - Initializes IMU heading tracking and camera capture at **640×480 and 30 FPS**.
  - Configures the LiDAR packet parser to extract distance measurements at **0°, 45°, 90°, 135°, and 180°**.
  - Waits for the physical start button to be pressed before starting the robot.
  - Sets the motor to the wall-following speed of **1620** after the start button is pressed.
- **Next State**: The robot performs its startup positioning sequence and then transitions to **WALL_FOLLOW**.

### WALL_FOLLOW

- **Function**: Main driving state. The robot follows the walls using camera-based contour detection and a PD controller.
- **Controller**: Uses the difference between the left and right wall contour areas:

  `error=(leftArea−rightArea)/(leftArea+rightArea)`

  The PD controller calculates a steering correction using proportional gain **Kp = 30** and derivative gain **Kd = -2.5**. Steering correction is limited to **±40°**.
- **Operations**:
  - Detects black wall regions using **LAB color thresholding**.
  - Uses two camera regions of interest (ROI1 and ROI2) to estimate the left and right wall positions.
  - Requires the wall-loss condition to remain active for **5 consecutive frames** before entering a turn.
  - Tracks IMU heading to determine whether the robot is travelling clockwise (CW) or counter-clockwise (CCW).
- **Transitions**:
  - **To PILLAR_AVOID**: Occurs when a red or green pillar is detected with an area greater than **MIN_REACT_AREA (500)**.
  - **To CORNER_TURN**: Occurs when either wall contour area falls below **1000** for **5 consecutive frames**, provided the required time has elapsed since the previous turn.
  - **To END_RUN**: The run-ending condition is activated when the relative IMU heading exceeds approximately **1040°**. After **30 consecutive frames** and a heading beyond **1070°**, the robot stops.

### PILLAR_AVOID

- **Purpose**: Detects and avoids colored obstacle pillars using HSV color thresholding and camera-based position tracking.
- **Detection**:
  - Identifies red and green pillars using separate HSV masks.
  - Selects the largest valid contour while rejecting small noise and objects above the minimum pillar height.
  - Determines the pillar's center position (`active_cx`) and vertical position (`active_cy`).
- **Control Logic**:
  - Uses different target positions for each pillar color: **RED_TARGET_CX = 90** and **GREEN_TARGET_CX = 550**.
  - Uses the detected pillar position to calculate a proportional steering correction.
  - The correction is scaled using the pillar's vertical position to adjust steering based on distance.
  - Steering correction is limited to **±40°**.
- **Color Bias**:
  - Uses the detected lap direction, pillar color, and pillar position to determine which side of the pillar the robot should recover toward.
  - Recovery can be classified as **LIGHT, NORMAL, or HEAVY** depending on the pillar configuration.
- **Recovery Mode**:
  - Activates after the pillar is no longer reliably detected.
  - Uses wall contour areas, time limits, balance measurements, and the previous pillar position to recover the robot back toward the correct driving path.
- **Transitions**:
  - **To WALL_FOLLOW**: Occurs after the pillar has been absent for **8 frames** and recovery conditions are satisfied.
  - **To CORNER_TURN**: Can occur when recovery determines that a corner has been reached or when a recovery timeout/side condition is satisfied.
  - **To PILLAR_AVOID**: Remains active or resets when another pillar is detected during recovery.

### CORNER_TURN

- **Purpose**: Performs predetermined approximately 90° corner turns based on which wall contour triggered the turn.
- **Control Logic**:
  - Runs the motor at **CORNER_TURN_MOTOR_VALUE (1620)**.
  - Uses **57°** steering for left turns and **107°** steering for right turns.
  - If both sides trigger the turn condition, the previous turn direction is used to select the direction.
  - Increments `turn_count` whenever the robot enters the corner-turn state.
  - Increments `lap_count` every **4 turns**.
- **Turn Exit**:
  - **Vision Mode** is currently active because `TOGGLE_GYRO_TURN = False`.
  - The robot normally exits when:
    - The wall contour that triggered the turn grows above **2500**,
    - The robot has turned for at least **0.5 seconds**, and
    - The wall areas are sufficiently balanced.
  - A maximum turn time of **10 seconds** prevents the robot from remaining in the turning state indefinitely.
  - **Gyro Mode**, if enabled, can instead exit when the absolute turn heading falls below **15°**.
- **Transitions**:
  - **To WALL_FOLLOW**: Occurs when the turn exit conditions are satisfied or the maximum turn time is reached.
  - **To PILLAR_AVOID**: Occurs if a new colored pillar is detected during the turn and recovery override is not active.

### START_RUN

- **Purpose**: Performs the initial movement and positioning sequence before normal autonomous driving begins.
- **Operations**:
  - Uses LiDAR measurements at **0° and 180°** to determine the robot's starting orientation.
  - Uses the IMU to monitor the robot's rotation during the positioning sequence.
  - Performs a sequence of forward and reverse movements with maximum steering to orient the robot correctly.
  - Uses different movement sequences depending on whether the robot is facing left or right.
- **Next State**: Once the startup positioning sequence is complete, `start_run` is set to `False` and the robot enters the normal state machine beginning with **WALL_FOLLOW**.

### END_RUN & STOP

- **Purpose**: Safely stops the robot after the required number of laps/turns has been completed.
- **Detection**:
  - Continuously monitors the accumulated relative IMU heading.
  - Activates the end-run counter after the relative heading exceeds approximately **1040°**.
  - After **30 frames** with the required heading maintained, the robot stops.
- **Actions**:
  - Returns the steering to the default position of **82°**.
  - Sets the motor to the neutral value of **1500**.
  - Releases the camera, closes the Arduino serial connection, and destroys OpenCV windows.
  - Ensures the motor is stopped and steering is centered in the final cleanup routine.
  
---

## 3. Threshold & Control Constants

| Constant | Value | Unit / Description |
| :--- | :--- | :--- |
| `WALL_FOLLOW_MOTOR_VALUE` | `1622` | Forward driving speed pulse width |
| `LEFT_ENTER_TURN_THRESH` | `1000` | Area drop threshold for corner entry |
| `ENTER_CONFIRM_FRAMES` | `5` | Debounce frame count before turning |
| `PILLAR_EXIT_FRAMES` | `8` | Consecutive clear frames required to exit avoid mode |
| `MIN_REACT_AREA` | `800` | Minimum pillar contour area to trigger avoidance |
| `TURN_LIMIT` | `12` | Total corners completed before terminating run |
| `Kp` / `Kd` | `15` / `-1` | PD parameters for wall following |

# Testing
All of our testing can be found in our engineering journal [here](https://docs.google.com/document/d/1yOxLSaLgVKeupWdl-JZPw-9g1dGKT5EjSAjHi6xOg-0/edit?tab=t.0)

# Performance Videos

## Open Challenge Video
Our open challenge video can be found on our youtube [here](https://youtu.be/NveL-KeYepw)

## Obstacle Challenge Video
Our obstacle challenge video can be found on our youtube [here](https://youtu.be/7QU7L7XVNVw)

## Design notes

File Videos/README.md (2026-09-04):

## This folder contains links to the google drive that contains the videos for documentation as backup in case of uncertainties

Access the google drive [here](https://drive.google.com/drive/u/0/folders/1oEr3LcG8tWddi14lOyDrDPx_9I_fGc4H)

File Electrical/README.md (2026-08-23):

## This is the readme for the Electrical folder. In here will be the explanation for the circuit and any relevant variations; As well as reasoning behind our electronic choices .
---

## Schematic


---

## Subsystems Overview and Electronics & Wiring

### 1. Power Distribution
* **Main Power Source:** 3S LiPo Battery (11.1V, 2200mAh) acts as the source of main power for the system by means of a Master Rocker Switch.
* **Logic Power (5V Rail):** In-line 5V Voltage Regulator reduces the 11.1V battery voltage to supply power to the Raspberry Pi 5 via the USB-C PWR port.
* **Actuators Power:** Furitek Lizard Pro ESC is powered directly from the battery bus. Its built-in 6V/3A BEC regulates power to the actuators and peripheral logic.

---

### 2. Microcontroller & Compute Units

#### **Raspberry Pi 5 (High-Level Computer Vision Controller)**
* In charge of high-level computer vision, image processing, and path planning.
* **Camera:** Interfaced using the MIPI CSI port to a Raspberry Pi camera for lane detection and color code reading.
* **Serial Bridge:** Interfaced using a USB 2.0 connection to the low-level motor controller.

#### **Arduino Nano v2.3 (Low-Level Motor Controller)**
* In charge of real-time motor control and real-time PWM execution.
* **ESC Signal:** Sends PWM control signals through pin D4 to the ESC.
* **Servo Signal:** Controls the steering mechanism using PWM signals on pin D3.
* **Power:** Powered through the USB rail / Power bus interfacing to the main controller hub.

---

### 3. Actuators & Motors
* **Primary Motor:** Furitek Micro Komodo 1212 (3450KV) Brushless DC Motor connected through three phase leads (MOTOR A, B, C).
* **ESC:** Furitek Lizard Pro 2S-4S LiPo ESC (45A continuous / 180A burst rating) for Brushless DC motor commutation.
* **Steering Motor:** Standard 3-pin PWM Servo Motor interfaced to pin D3 of the Arduino Nano.

---

### 4. Sensors and Future Hardware Expansion
* **Vision:** Raspberry Pi camera for visual tracking in real time.
* **D500 LiDAR (Not Connected / Plugged in):**
  * **Status:** The D500 LiDAR sensor with JST ZH-5 and JST ZH-6 connectors for DATA1, SPEED CONTROL1, and POWER & GND1 is mounted on the chassis but not yet plugged in.
  * **Future Scope:** Will be connected to the Raspberry Pi’s UART or USB port for 2D/3D obstacle grid detection and wall-following algorithms.

## Why we changed the robot
Our first robot had a ton of problems and emphasize on a ton, to see them all you can read our engineering journal [here](https://docs.google.com/document/d/1yOxLSaLgVKeupWdl-JZPw-9g1dGKT5EjSAjHi6xOg-0/edit?tab=t.0) where it provides information on each problem, the dates they appeared, and any solutions.
| *First Robot* |
| :---: |
|  |

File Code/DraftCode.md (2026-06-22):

## Simple foundation for our code

### Raspberry-Arduino Communication (Arduino)
```cpp

#include <Arduino.h>
#include <ctype.h>
#include <string.h>
#include <stdlib.h>
#include <Servo.h>
#include <Arduino_BMI270_BMM150.h> // Include Rev2 IMU Library

static const size_t LINE_MAX = 16;    // max length of command (excluding the terminate character '\0')
static char   lineBuf[LINE_MAX + 1];
static size_t lineLen = 0;
static const char SOC = '@';          // start-of-command marker
static bool   inCommand = false;
Servo Steering_Servo;
Servo lizardESC;
// --- IMU Variables ---
float heading = 0.0;
float gyroZBias = 0.0;
unsigned long lastTime;

void SetRGBLED(int state)//0 - Off; 1 - RED; 2 - Green; 3 - Blue
{
  if(state == 0)
  {
    digitalWrite(LEDR, HIGH);
    digitalWrite(LEDG, HIGH);
    digitalWrite(LEDB, HIGH);
  }
  else if(state == 1)
  {
    digitalWrite(LEDR, LOW);// Red ON
    digitalWrite(LEDG, HIGH);// Green OFF
    digitalWrite(LEDB, HIGH);// Blue OFF
  }
  else if(state == 2)
  {
    digitalWrite(LEDR, HIGH);// Red OFF
    digitalWrite(LEDG, LOW);// Green ON
    digitalWrite(LEDB, HIGH);// Blue OFF
  }
  else if(state == 3)
  {
    digitalWrite(LEDR, HIGH);// Red OFF
    digitalWrite(LEDG, HIGH);// Green OFF
    digitalWrite(LEDB, LOW);// Blue ON
  }
}

void setup() {
  Serial.begin(115200);
  Serial.setTimeout(10);
  Steering_Servo.attach(3);
  lizardESC.attach(4);
  lizardESC.writeMicroseconds(1500); // 1500us is typically neutral
  delay(2000);

  // Initialize the RGB pins as outputs
  pinMode(LEDR, OUTPUT);
  pinMode(LEDG, OUTPUT);
  pinMode(LEDB, OUTPUT);

  // Turn all colors OFF immediately at startup
  SetRGBLED(0);

  // Initialize the Rev2 IMU
  if (!IMU.begin()) { //Failed to initialize Rev2 IMU!
    SetRGBLED(1);
    while (1); 
  }

  // Gyro Calibration: Keep the car perfectly still when booting up!
  SetRGBLED(3);
  int samples = 500;
  float sum = 0;
  int validSamples = 0;
  for (int i = 0; i < samples; i++) {
    if (IMU.gyroscopeAvailable()) {
      float x, y, z;
      IMU.readGyroscope(x, y, z);
      sum += z;
      validSamples++;
    }
    delay(10);
  }
  gyroZBias = (validSamples > 0) ? sum / validSamples : 0.0;
  
  //Calibration Complete.
  SetRGBLED(2);
  delay(1000);
  SetRGBLED(0);
  
  lastTime = micros();
}

static void handleCommand(char* command) {
  if (!command || command[0] == '\0') return;

  // If the line includes '\r' (CRLF), terminate at it
  char* cr = strchr(command, '\r');
  if (cr) *cr = '\0';

  // Trim leading spaces
  while (*command && isspace((unsigned char)*command)) command++;
  if (*command == '\0') return;

  // Command type
  char type = *command++;

  // --- Handle Heading request immediately before integer parsing ---
  if (type == 'H') {
    Serial.println(heading);
    return;
  }

  // Parse integer (For S and M commands)
  char* endp = nullptr;
  long value = strtol(command, &endp, 10);

  // Must have at least one digit for S and M commands
  if (endp == command) return;

  if (type == 'S') {
    if (value < 0 || value > 180) return;

      Steering_Servo.write(value);

  } else if (type == 'M') {
    if (value < 1000 || value > 2000) return;
      lizardESC.writeMicroseconds(value);
  }
}

void loop() {
  // 1. Read exactly ONE available byte per loop execution pass
  if (Serial.available() > 0) {
    char c = (char)Serial.read();

    if (c == SOC) {
      // Start a fresh command tracking window
      inCommand = true;
      lineLen = 0;
    } 
    else if (inCommand) {
      // Only process characters if we have successfully parsed a valid SOC ('@')
      if (c == '\n') {
        lineBuf[lineLen] = '\0';
        handleCommand(lineBuf);
        inCommand = false;
        lineLen = 0;
      } 
      else if (lineLen < LINE_MAX) {
        lineBuf[lineLen++] = c;
      } 
      else {
        // Buffer Overflow protection: dump frame, reset, wait for next '@'
        inCommand = false;
        lineLen = 0;
      }
    }
  }

  // =======================================================================
  // 2. Background Time-Critical Work: IMU Tracking
  // =======================================================================
  if (IMU.gyroscopeAvailable()) {
    float x, y, z;
    IMU.readGyroscope(x, y, z);

    // Remove baseline sensor noise drift
    z -= gyroZBias;

    // Ignore micro-vibrations below a small deadzone threshold
    if (abs(z) < 0.1) z = 0.0; 

    // Compute elapsed time (dt) in seconds
    unsigned long currentTime = micros();
    float dt = (currentTime - lastTime) / 1000000.0;
    lastTime = currentTime;

    // Integrate angular velocity over time
    heading -= z * dt; 
  }
}
```
### Camera Capture & ROI Drawing
```py
import cv2
from picamera2 import Picamera2
from time import sleep

# --- Camera init ---
picam2 = Picamera2()
picam2.preview_configuration.main.size = (640, 480)
picam2.preview_configuration.main.format = "RGB888"
picam2.preview_configuration.controls.FrameRate = 30
picam2.preview_configuration.align()
picam2.configure("preview")
picam2.start()

# --- ROIs (x1, y1, x2, y2)  ---
ROI1 = [20, 170, 240, 220]     # Left ROI
ROI2 = [400, 170, 620, 220]    # Right ROI

def draw_roi(img, roi, color=(0, 255, 255), thickness=2, label=None):
    x1, y1, x2, y2 = roi
    cv2.rectangle(img, (x1, y1), (x2, y2), color, thickness)
    if label:
        cv2.putText(img, label, (x1, max(0, y1 - 8)),
                    cv2.FONT_HERSHEY_SIMPLEX, 0.5, color, 1, cv2.LINE_AA)

# --- Continuously capture and display frame, with ROIs ---
while True:
    frame = picam2.capture_array()  # continuously capture frame

    # show left and right ROI in the frame displayed
    draw_roi(frame, ROI1, label="ROI1 (Left)")
    draw_roi(frame, ROI2, label="ROI2 (Right)")

    cv2.imshow("Camera with Left/Right ROI", frame)  # continuously display

    if cv2.waitKey(1) & 0xFF == ord('q'):
        break

cv2.destroyAllWindows()
picam2.stop()
```

### Wall Detection inside the ROI's

```py

import cv2
import numpy as np
from picamera2 import Picamera2
from time import sleep

# --- Camera init ---
picam2 = Picamera2()
picam2.preview_configuration.main.size = (640, 480)
picam2.preview_configuration.main.format = "RGB888"
picam2.preview_configuration.controls.FrameRate = 30
picam2.preview_configuration.align()
picam2.configure("preview")
picam2.start()
sleep(0.5)

# --- ROIs (x1, y1, x2, y2) ---
ROI1 = [20, 170, 240, 220]     # Left ROI
ROI2 = [400, 170, 620, 220]    # Right ROI

def draw_roi(img, roi, color=(0, 255, 255), thickness=2, label=None):
    x1, y1, x2, y2 = roi
    cv2.rectangle(img, (x1, y1), (x2, y2), color, thickness)
    if label:
        cv2.putText(img, label, (x1, max(15, y1 - 8)),
                    cv2.FONT_HERSHEY_SIMPLEX, 0.5, color, 1, cv2.LINE_AA)

def find_wall_area_lab(frame_rgb, roi, lab_lower, lab_upper, min_contour_area=50):
    """
    Returns:
      area_max: area of largest contour inside ROI (0 if none)
      contour_max: contour points (shifted to full-frame coordinates) or None
      mask_roi: binary mask for ROI (for optional debug display)
    """
    x1, y1, x2, y2 = roi
    roi_bgr = frame_rgb[y1:y2, x1:x2]  # picamera2 gives RGB, but OpenCV ops below work either way for Lab conversion
    lab = cv2.cvtColor(roi_bgr, cv2.COLOR_RGB2Lab)
    lab = cv2.GaussianBlur(lab, (7, 7), 0)

    mask = cv2.inRange(lab, lab_lower, lab_upper)

    # Clean up noise
    kernel = np.ones((3, 3), np.uint8)
    mask = cv2.morphologyEx(mask, cv2.MORPH_OPEN, kernel, iterations=1)
    mask = cv2.morphologyEx(mask, cv2.MORPH_CLOSE, kernel, iterations=2)

    contours, _ = cv2.findContours(mask, cv2.RETR_EXTERNAL, cv2.CHAIN_APPROX_SIMPLE)

    area_max = 0
    contour_max = None
    for c in contours:
        a = cv2.contourArea(c)
        if a > area_max and a >= min_contour_area:
            area_max = a
            contour_max = c

    # Shift contour to full-frame coordinates for drawing on the original frame
    if contour_max is not None:
        contour_max = contour_max + np.array([[[x1, y1]]], dtype=np.int32)

    return area_max, contour_max, mask

# --- LAB threshold for "black wall" (tune this!) ---
# In Lab: L low = dark. Start conservative and tune by observing mask output.
LAB_BLACK_LOWER = np.array([0,   0,   0], dtype=np.uint8)
LAB_BLACK_UPPER = np.array([70, 255, 255], dtype=np.uint8)

# --- Main loop ---
while True:
    frame = picam2.capture_array()  # RGB image

    # Detect left/right wall areas
    leftArea, leftContour, leftMask = find_wall_area_lab(frame, ROI1, LAB_BLACK_LOWER, LAB_BLACK_UPPER)
    rightArea, rightContour, rightMask = find_wall_area_lab(frame, ROI2, LAB_BLACK_LOWER, LAB_BLACK_UPPER)

    # Draw ROIs
    draw_roi(frame, ROI1, label="ROI1 (Left)")
    draw_roi(frame, ROI2, label="ROI2 (Right)")

    # Draw largest contour (wall) if found
    if leftContour is not None:
        cv2.drawContours(frame, [leftContour], -1, (0, 255, 0), 2)
    if rightContour is not None:
        cv2.drawContours(frame, [rightContour], -1, (0, 255, 0), 2)

    # Show numeric areas on the frame
    cv2.putText(frame, f"leftArea: {int(leftArea)}", (10, 30),
                cv2.FONT_HERSHEY_SIMPLEX, 0.7, (255, 255, 255), 2, cv2.LINE_AA)
    cv2.putText(frame, f"rightArea: {int(rightArea)}", (10, 60),
                cv2.FONT_HERSHEY_SIMPLEX, 0.7, (255, 255, 255), 2, cv2.LINE_AA)

    # Display main view
    cv2.imshow("Wall Detect (Left/Right ROI)", frame)

    # Optional: show masks for tuning thresholds (uncomment if needed)
    # cv2.imshow("Left ROI Mask", leftMask)
    # cv2.imshow("Right ROI Mask", rightMask)

    if cv2.waitKey(1) & 0xFF == ord('q'):
        break

cv2.destroyAllWindows()
picam2.stop()
```

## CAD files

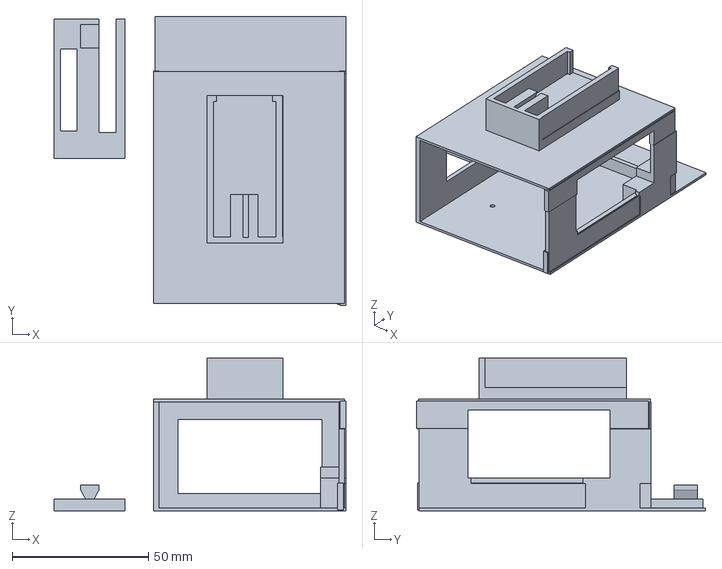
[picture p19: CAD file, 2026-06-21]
3d-prints/Version-2/Main housing 6.14.26.3mf
107.0 x 106.0 x 56.0 mm

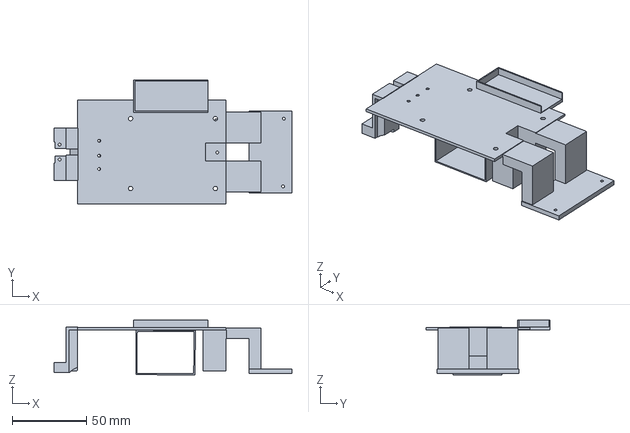
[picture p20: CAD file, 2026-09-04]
3d-prints/Version-2/Bottom chassis 8.30.26.3mf
160.0 x 83.5 x 36.8 mm

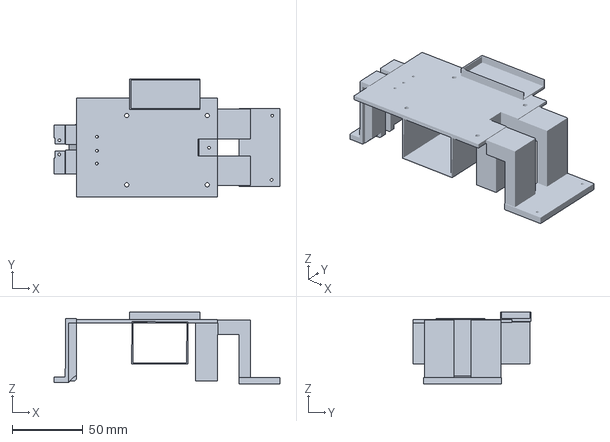
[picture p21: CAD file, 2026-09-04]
3d-prints/Version-2/Bottom chassis 8.31.26.3mf
160.0 x 83.8 x 50.8 mm

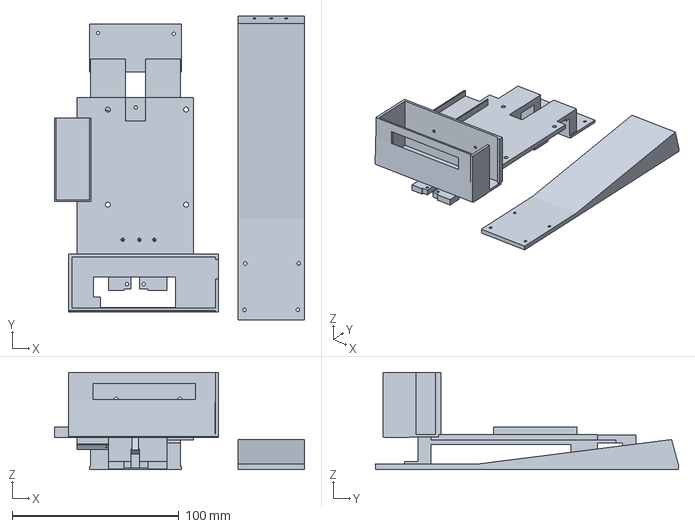
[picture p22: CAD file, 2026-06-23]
3d-prints/Version-2/chassis and camera stand 6.23.26.3mf
150.0 x 182.1 x 58.4 mm

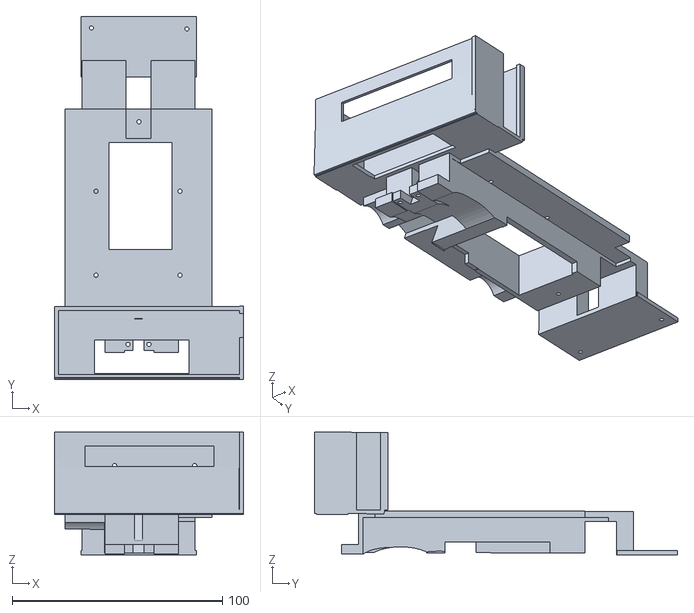
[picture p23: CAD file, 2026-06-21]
3d-prints/Version-2/bottom chassis 6.21.26.stl
90.0 x 173.0 x 58.4

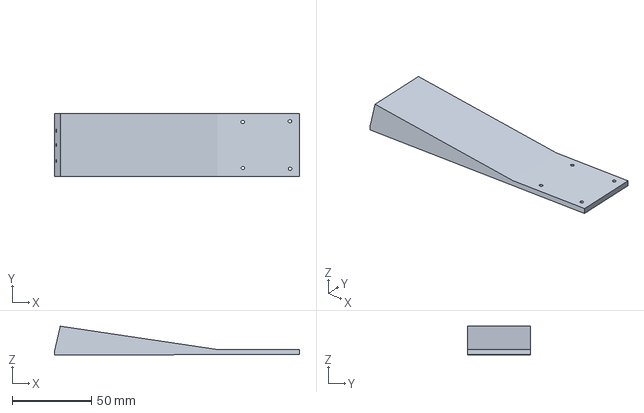
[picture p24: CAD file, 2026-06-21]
3d-prints/Version-2/Camera stand 6.14.26.3mf
154.6 x 40.0 x 18.1 mm

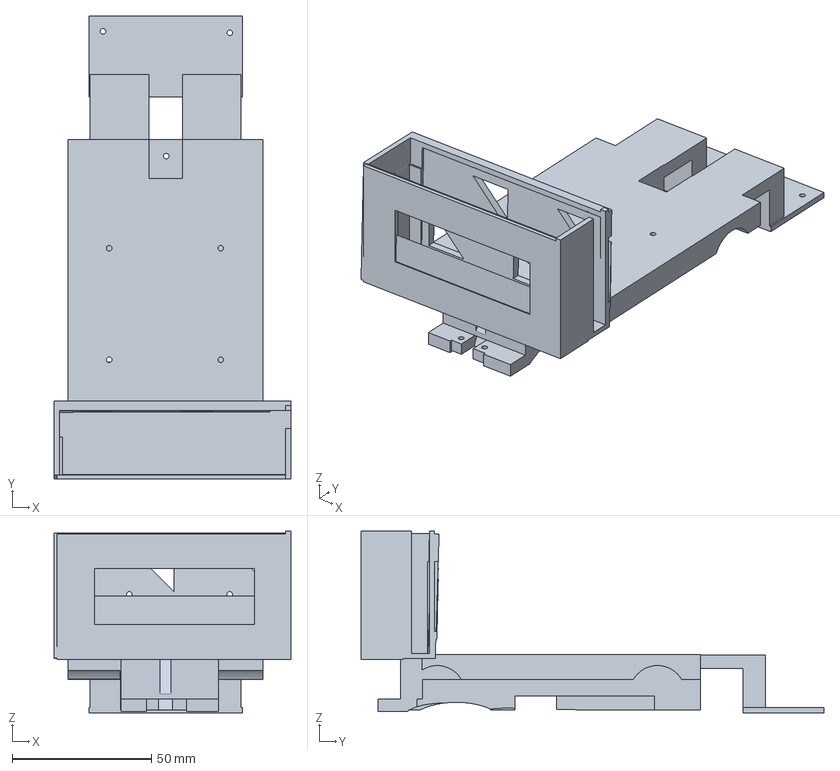
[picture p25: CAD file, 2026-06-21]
3d-prints/Version-2/bottom chassis 6.14.26.3mf
85.0 x 166.0 x 65.3 mm

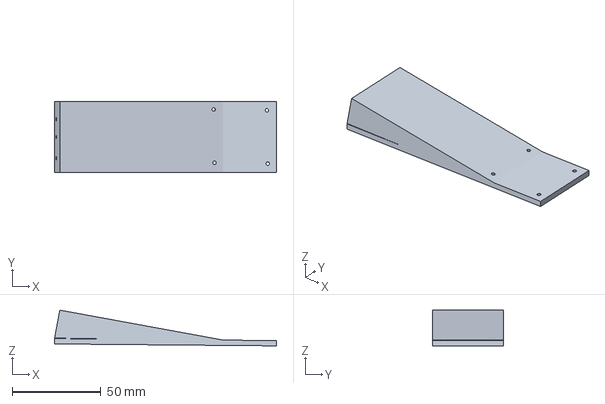
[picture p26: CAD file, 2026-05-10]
3d-prints/Version-2/Camera stand v2.3mf
125.0 x 40.0 x 20.1 mm

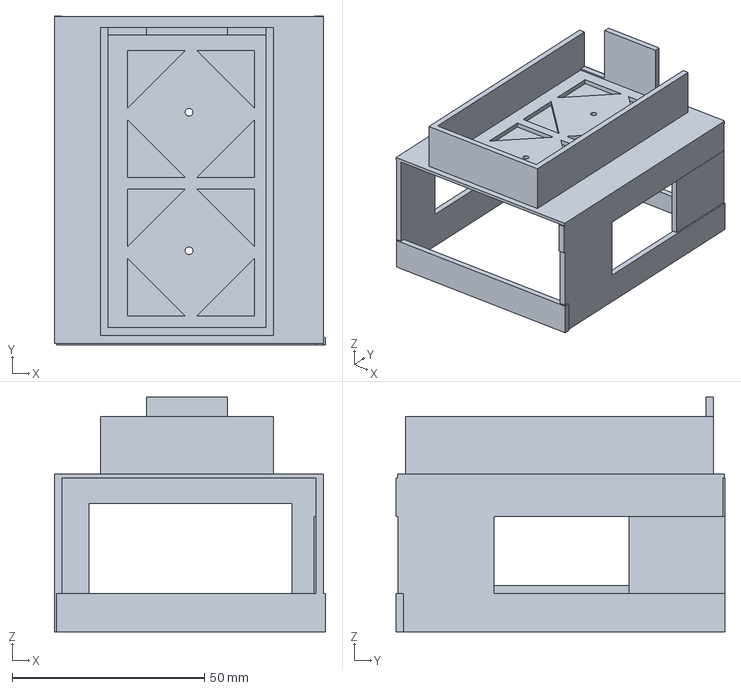
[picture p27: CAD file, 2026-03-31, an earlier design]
3d-prints/Version-1/Main housing part.3mf
70.5 x 85.5 x 61.0 mm

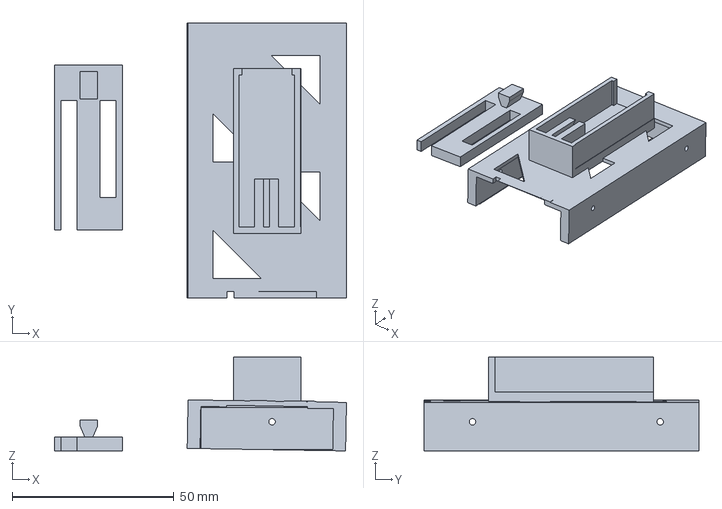
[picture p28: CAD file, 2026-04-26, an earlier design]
3d-prints/Version-1/Arduino housing v1.4.3mf
90.2 x 85.0 x 29.0 mm

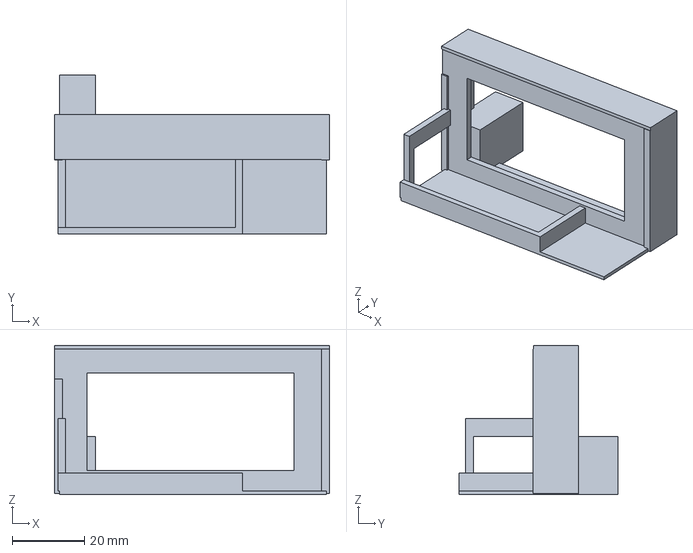
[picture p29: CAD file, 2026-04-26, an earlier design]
3d-prints/Version-1/Arduino housing v1.3.3mf
76.0 x 44.0 x 41.2 mm

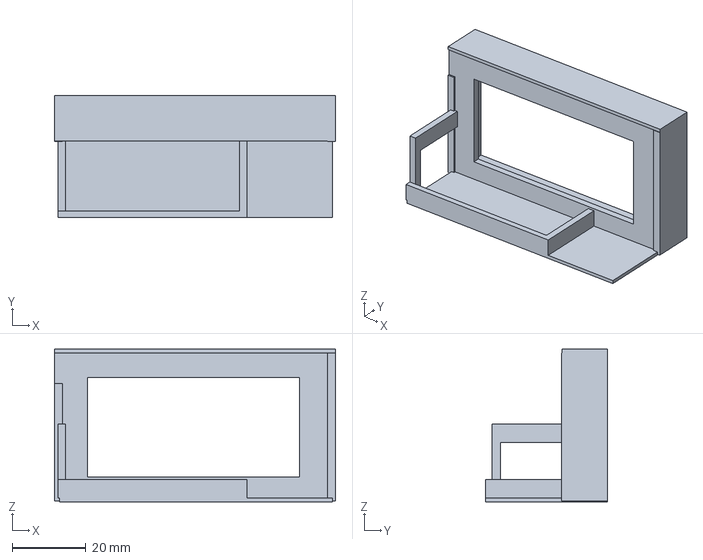
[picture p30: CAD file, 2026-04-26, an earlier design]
3d-prints/Version-1/Arduino housing v1.2.3mf
76.0 x 33.0 x 41.2 mm

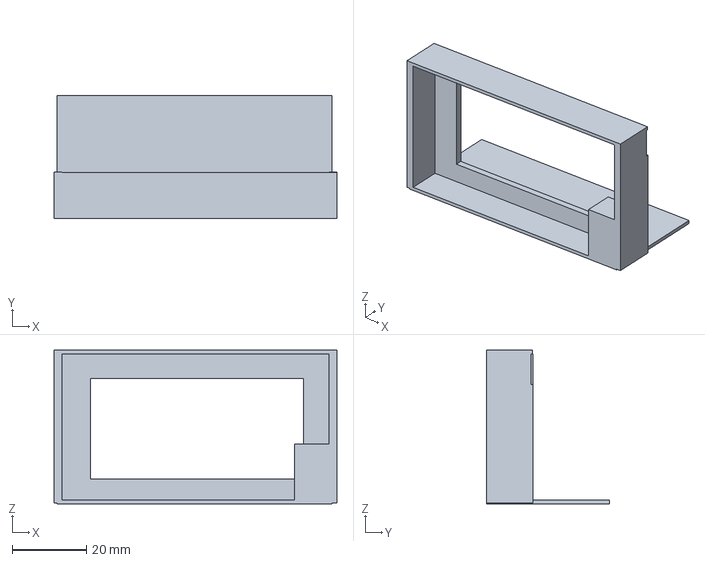
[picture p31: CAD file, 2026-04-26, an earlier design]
3d-prints/Version-1/Chassis Front v1.3mf
76.0 x 33.0 x 41.2 mm

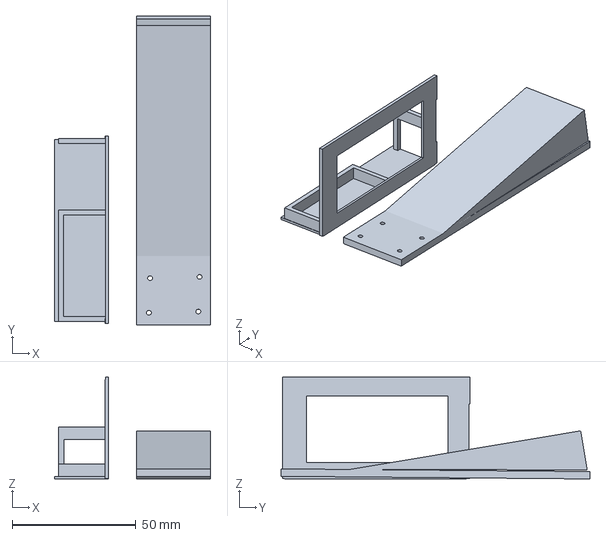
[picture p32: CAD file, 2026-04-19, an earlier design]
3d-prints/Version-1/Camera stand v1.2.3mf
63.3 x 125.0 x 41.2 mm

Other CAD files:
3d-prints/Version-2/bottom chassis and camera stand 6.23.26.3mf
3d-prints/Version-1/camera stand v1.1.3mf
3d-prints/Version-1/bottom chassis v1.2.3mf
3d-prints/Version-1/upper chassis v1.2.3mf
3d-prints/Version-1/Battery top half.3mf
3d-prints/Version-1/Camera Stand.3mf
3d-prints/Version-1/bottom chassis v1.1.3mf
3d-prints/Version-1/bottom chassis v1.1.stl
3d-prints/Version-1/bottom chassis.3mf

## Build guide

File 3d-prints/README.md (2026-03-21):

## This is our 3d prints folder where you can find all of our renditions of 3d models from our first drafts to our final products.

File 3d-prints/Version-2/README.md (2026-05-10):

This file includes some revised second versions for some of our parts including the camera

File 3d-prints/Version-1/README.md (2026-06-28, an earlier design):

# These are the parts of our first version for the 3d-prints

## Arduino Housing
### Version 1
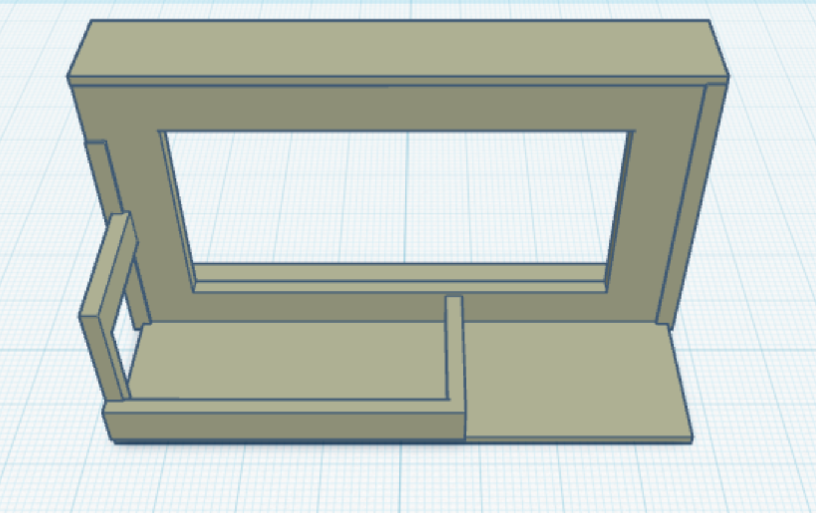
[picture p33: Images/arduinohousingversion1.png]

Version 1 of our arduino housing also included the front of the raspi housing and a little part for the arduino.

### Version 1.2
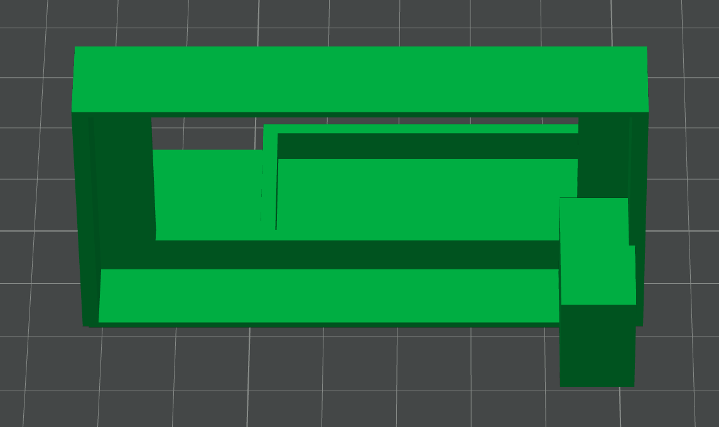
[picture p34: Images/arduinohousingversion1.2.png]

Version 1.2 of our arduino housing had the part for the arduino slightly larger so the arduino could fit better, and a block on the back to help support the raspberry pi.

### Version 1.3
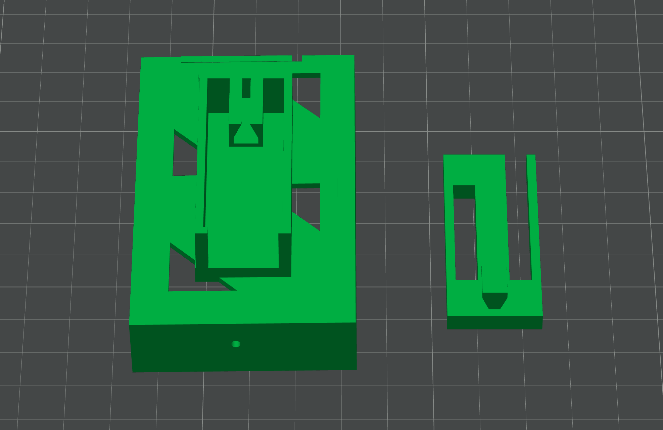
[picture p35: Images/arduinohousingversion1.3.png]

Version 1.3 of our arduino housing was a complete redesign. We shifted the housing to be on top of the robot for an easier way to access the ports and added a top little "hat" that wuld secure everything together.

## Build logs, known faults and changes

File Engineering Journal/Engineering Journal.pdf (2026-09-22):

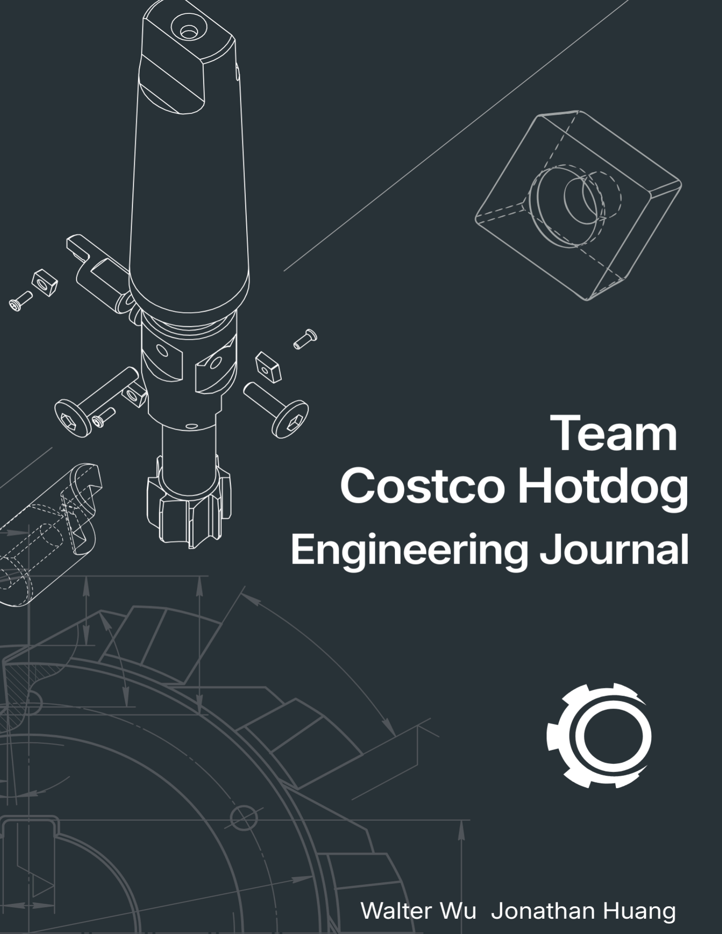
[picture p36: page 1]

## Team Costco Hotdog Future Engineers 2026 Engineering Journal

## Table of Contents

## 1. Introduction

We are team Costco Hotdog, participating in the Future Engineers category of WRO 2026, and from the Explorer Robotics club based in Canada.
This document is designed to showcase our decisions, tests, failures, iterations, reasoning for each component, robot reproducibility, and the main process we took to engineer our robot for the competition.

## 1.1 Meet the team

Our team, Costco Hotdog is based off of a infamous $1.50 CAD hotdog in our country. We are composed of two members and our coach. Our group is based out of the Durham region in Ontario, Canada.
The two members of our team are Jonathan Huang and Walter Wu. We are both going into our second year of high school. Walter is enrolled in the AMP for All Saints studying media arts and Jonathan is attending Notre Dame and likes to learn about the origins of aerospace mechanisms and discovering how they work. Jonathan is the main programmer for all the software and helps a lot with any mechanical or hardware problems fixing most of the problems as soon as they arise. Walter is the main person behind the documentation and hardware and mechanical engineering.

## 1.2 Challenge

WRO Future Engineers is a competition where teams must design, build, and program a fully autonomous driving robot that completes two challenges. The robot by itself will navigate a track, following any random sections while avoiding obstacles and staying within the track boundaries. The track itself can include obstacles, a parallel parking challenge, and changing track lengths. The future engineers category is split up into three main challenges, the open challenge, obstacle challenge, and documentation.

The main challenge is making the robot reliable enough to handle changes in the track while moving quickly and accurately. Any mistake on the steering mechanism, the sensors or programming may lead to our robot colliding with the walls or failing to detect objects and any other uncertainties that come with the problem greatly influence the way it is solved. The objective of our team in solving the problem is to have a robot which will be able to navigate the path and complete the circuit without any faults.

## 2. Design Goals

The Future Engineers rulebooks provides many well rules that influenced our designing for the robot, those include:
- Robot dimensions
- Motor limitations
- Wired communication requirements
- Track requirements
- Starting Requirements
- Sensors/cameras
- Power requirements
- Parking requirements
- Autonomous operation
- Drive System limitations

The three main rules contributing to our design goals were the parking requirements, drive system limitations, and the starting requirements:

The starting requirements are particularly strict as they indicate that the robot must begin completely switched off, only one button/switch is used to turn it on, and it must enter a waiting state until another button input to start. This is not inherently complicated but not only can it fail easily as evident in previous infractions in past competitions but when it does the consequences can severely affect the scoring.

The next problem is the parallel parking requirements, teams have an option whether or not to incorporate the parking in their run since the challenge is so competitive it is difficult to get a high score in comparison to other teams without the twenty-two points that the parking provides. The parking itself can be treated as a challenge separate to the open or obstacle challenges not only because it is optional, but because of the requirements. The parking lot is only 1.5x the length of our robot and deciding whether or not the parallel parking was successful comes down to a difference of 2cm.

The rulebook provides specific limitations surrounding the drive systems and included a note on how previous teams have received a dock in points or disqualification because they did not adhere to the rules. The drive system must be physically connected either through a gearbox or other method, and it is prohibited to use one motor for each side. This is something every team has to consider when designing their drive systems.

## 2.1 Brainstorming & Initial Concepts

Before we made the final design, there were other designs that we had to consider, ranging from mechanical to electrical as well as software solutions. The purpose of the brainstorming process was to come up with a design that was able to effectively navigate through the competition environment and yet was still easy to construct, reproduce and modify.

Concept A – Front Wheel Steering

Our first concept was a front wheel steering design from cars where the front wheels turn and the rear wheels provide the power.

Advantages:
- It is more like the typical car design.
- Better ability to control the direction of the robot.
- Stable when going straight.
- The steering is separate from the motor that drives the robot. Disadvantages:
- More mechanically complex.
- Needs a steering mechanism and servo mechanism.
- Has a larger turning circle.
- Difficult to make quick corrections around objects.

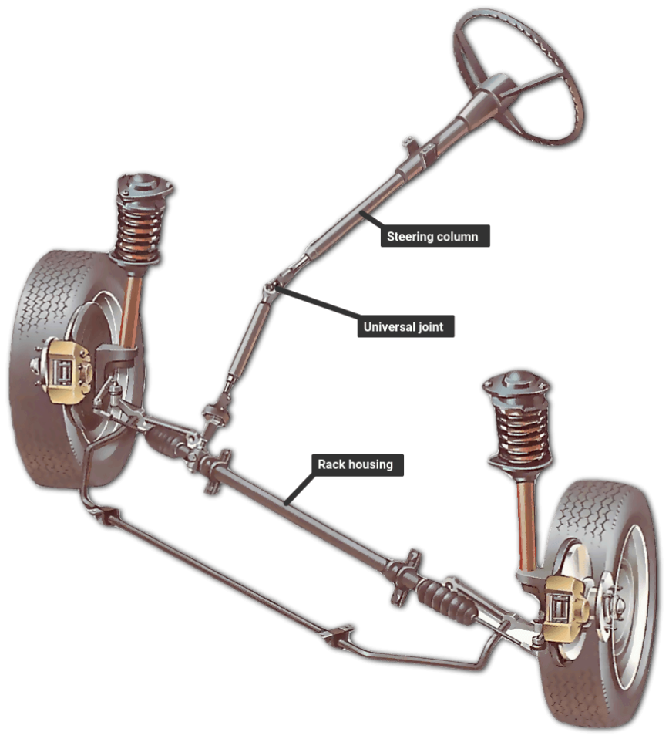
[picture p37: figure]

Figure 1. A picture of a real world application of the front wheel steering concept.

Concept B – Differential Drive

The second concept consisted of two independently powered wheels that would enable the robot to turn based on the different speeds and directions of the wheels on either side.

Advantages:
- Mechanically simple
- Relatively few moving parts
- Good ability to turn
- Easy control using software
- Our team was familiar with this kind of driving style from our previous competitions using EV3
Disadvantages:
- Different from conventional car steering
- Can lead to wheel slippage when turning
- Not well suited to our driving behavior requirement
- Can be difficult to position precisely on some terrains

Concept C – Front Steering with Rear-Wheel Drive

We have also considered the advantages of combining the strengths of the two methods with front wheel steering combined with a drive motor connected to the rear wheels.

Advantages:
- Better control on driving route
- Relatively simple drivetrain
- Predictable turning
- Better handling when maneuvering through obstacles Disadvantages:
- More complex than differential drive
- Steering system has to be properly aligned
- Calibration of servo positions required

Finally, based on evaluation of the concepts, we have chosen to use front wheel steering and rear-wheel drive method due to its superior performance characteristics in our anticipated competition setting, as well as to try something new while being able to talk to people who were already familiar with this kind of drive train, i.e our teammates and coach.

Chassis and Wheel Arrangement

Other types of chassis layout were also taken into consideration. Many different wheel sizes, wheelbases, and locations of battery and electronic components were tried out. With a shorter chassis, tighter turns can be made but would become unstable at high speeds, while a longer chassis will give more stability to the chassis and space for components, but we would have to consider weight with everything. A good compromise was found with a compact layout which gave enough room for all the necessary hardware.

Sensor Placement

We had considered several locations for the sensor mix and matching the height, and distance from the front of the car. Mounting the camera at a higher point would help us capture the whole race track area whereas mounting at a lower location would help in getting consistent readings regarding the obstacles. The sensor could also have been mounted in the front area of the robot so that information regarding the obstacles would be captured well before reaching the obstacles.

The final placement was decided so as to capture the most important information, which would be the area in front of the robot; as well as the side walls.

Software Approaches

A number of navigation approaches were looked at, most importantly:

Fixed movement sequences: easy to program but unable to respond to unexpected situations or conditions.
Distance-based navigation: determines through distances when the robot needs to change direction or position itself.
Camera-based navigation: relies on the camera to find features in the course and the robot’s position.
Multiple sensors: relies on a variety of information sources to enable the robot to make better decisions.

We decided to use an approach based on sensors which combines the camera data and distances measurements as well as robot control data. This allows the Raspberry Pi 5 to analyze the surroundings and make decisions regarding navigation rather than executing preprogrammed actions.

Obstacle Avoidance Strategies

We also looked at different ways of navigating around obstacles. One such method was the use of a preset path, as in moving 50cm right when the robot sees a red pillar, but this would be less effective if there were any changes in the position of the robot. The other one is the continuous detection of the obstacle and calculating the correct steering angle.

Our decision on the strategy would be that the robot detects the environment and steers according to the sensor data, continuous detection and adaption. This makes the robot flexible in case of change in position or any other affections.

Final Design Decision

After evaluating all of the different designs, the one that offered the most balance between reliability, maneuverability, sensor detection, mechanical simplicity, and control via software was found. In the final design, the robot is equipped with a small chassis, front wheel steering, rear wheel drive, Raspberry Pi 5 computer, Arduino, and several sensors that gather data from the environment.

The Brainstorming process turned out to be incredibly useful as it made it possible for us to see the weaknesses of the initial designs before proceeding to finalize the robot. Instead of using our first design concepts and changing the robot through trial and error, we evaluated several options and based on their advantages and drawbacks, came up with the final version of the robot.

## 3. Mechanical design

The mechanical design of the robot was completed through multiple iterations of prototyping, testing, and redesigning. Our primary objectives throughout the mechanical design process were to create a robot which was compact, steady, maneuverable, strong enough to withstand repeated testing, and capable of holding all the electrical sensors necessary for the competition.

The mechanical design kept changing as we encountered many problems through our testing. Among the major mechanical problems we encountered were those to do with wheel attachment, our undesirable center of gravity, the mounting of the BLDC motors, and the chassis design in itself. Rather than seeing this as failure and completely scratching previous ideas, we saw it as an opportunity to improve our design.

## 3.1 Chassis

The chassis provides the main structural frame of the robot and supports the drivetrain, steering system, battery, electronics, and sensors. We designed the chassis around the size limitations of the competition while leaving enough room for all of the required components.

Dimension | Dimension
Length | 21cm
Width | 10cm
Height | 22.5cm

Final dimensions were taken from the complete robot rather than estimates from early CAD designs

The chassis has been made mostly out of 3D printed parts, tape, screws, brackets, and other mechanical fasteners. Thanks to 3D printing, we were able to make and redesign custom parts quickly without making each of them manually.

The first issue which we have faced is that we underestimated how much time each 3D print would take. On March 29, 2026, we recognized that printing time was a big limitation. This was fixed by scheduling even more of our prints between classes, and designing them all before the next class would start so that we would be able to get our parts printed without compromising our progress.
Another early limitation was the lack of screws for assembling the mechanism. Between March 1 and April 19, 2026, this has been happening on a regular basis. It was pretty easily resolved by buying a set of screws in different sizes, but was a notable challenge in the beginning of creating our robot.
Mounting Points

The chassis houses mounting points for:
- Furitek Micro Komodo motor
- Furitek Lizard Pro ESC
- Steering servo
- Steering linkage
- Battery
- Raspberry Pi 5
- Arduino Nano
- Camera
- D500 LiDAR
- Wheels
The specific mounting locations were chosen in such a way that essential components could be mounted securely, without changing the center of gravity too much.

Chassis Strength

The chassis had to be able to handle the stresses of driving, turning, impact, and some replacement of components. While we tested the chassis, we noticed that certain parts were able to come loose after time passed. This included the wheels and the mounting screws used for the motor.

The problem with wheel attachment began on March 7, 2026. At times, the wheels would either loosen or come right off. This proved that simply mounting the wheels was not enough for competition.

Centre of Gravity

One of the most significant mechanical problems we faced was heavy wobbling even while taking shallow turns.

On May 24, 2026, it was observed that the center of gravity of the robot was exceedingly high; and because of that, the robot becomes very unstable, especially more while taking sharp steering turns. The earlier configuration was such that the robot had its weight more towards the front and high.

The redesigning of the chassis configuration helped in addressing this problem by relocating the battery towards the back of the robot, helping with counteracting the old front-heavy design and overall improved the weight distribution of the robot.

This redesigned layout solved the issue and proved to be effective in highlighting the fact that the mass distribution of the robot should also be taken into high consideration along with its dimensions.

## 3.2 Drive System

The robot uses a brushless drive system consisting of a Furitek Micro Komodo motor and Furitek Lizard Pro ESC. The drive system was selected to provide enough power for rapid acceleration while maintaining controllability during autonomous navigation.

The Micro Komodo BLDC motor was chosen because it gives adequate power output and can fit into the chassis easily due to its small size. The Lizard Pro ESC has been chosen to electronically control the brushless motor and allow the Raspberry Pi/Arduino to control the drive system.

Motor Mounting Problem

On May 5, 2026, we found out that the BLDC motor could potentially come loose while running. Once the screws holding the motor in place became loose, the pinion gear could detach itself from the other gears on the drivetrain. The loss of proper engagement meant that the robot couldn't perform something as simple as driving forward.

The solution was simple, we just needed to tighten the screws keeping the motor in place.

Although the solution was relatively simple, this was an important change from a mechanical point of view, since it showed that alignment of the drivetrain is equally as important as choosing the motor. It does not matter how strong your motor is if it cannot transmit the torque properly.

Drive Performance

The maximum speed and acceleration were calculated by testing and not by simply assuming manufacturer's specifications. The robot was tested in a controlled environment, and the time needed to cover known distances was measured.

The measured results are as follows:

Maximum speed: 32.23 m/s (100% throttle)

Acceleration: 5.89 m/s²

Average speed: 4.1 – 6.8 m/s (15-25% throttle)

### 3.3 Steering

The robot has a steering mechanism which is controlled by the servo. The servo manipulates the mechanical linkage which alters the orientation of the front wheels.

Component | Specification
Steering servo | HiTEC HS-5055MG Digital Micro Servo
Steering mechanism | Front wheel steering
Steering Linkage | Parallelogram Linkage
Maximum left angle | 42°
Maximum right angle | 122°
Centre angle | 82°

Steering Calibration

The theoretical center value of the servo was not considered as the inherently correct or right center value. We had tested the steering system and adjusted our software according to the physical center value of the wheels to find the actual "straight" position for the wheels.

For instance, the initially assigned command of 90 µs to the servo was assumed to be the center value. After testing, it was found that the center value is actually closer to ~66-67 µs.

Moreover, we also tested the maximum left and maximum right turning angles. After this, we programmed our software accordingly to ensure that the servo does not move outside the mechanically safe range.

Turn Radius

The turning radius of any robot is calculated mathematically by dividing the wheelbase of the vehicle by the sine of the steering angle.

(R = Wheelbase/ sin(Steering Angle))

For this mathematical method of calculating turn radius, we had calculated the turn radius or R to be ~17.8cm.

Radius = Wheelbase ÷ sin(Steering Angle)

Radius = 10.2 ÷ sin(35)

Radius = 10.2 ÷ 0.57357643635

Radius = 17.7831573154

But to figure out if that is actually the real world case, the turn radius can also be determined physically by making a complete 180 degrees turn and dividing the distance of the two points (the beginning and end of the U-Turn) by two.

With our try at the physical method, the turning radius was measured by commanding the robot to maintain a constant steering angle and measuring the path followed by the centre of the robot.

The turn radius measured in at approximately 18.5cm.

This measurement was important in deciding if the robot was capable of making the turns required in the strict competition course.

### 3.4 Mechanical Iterations

The mechanical design evolved considerably through the design process. The end product was not developed from one design; rather, a series of modifications were made based on problems that occurred during testing.

Version 1: Initial Chassis

The first chassis was designed for the basic drivetrain and steering needs. This chassis served as mounting points for our major components but had not yet been tested thoroughly.

Problem:

Through testing, we found that there were some problems with weight distribution, wheel attachment, and mounting points.

Modification:

We worked on the mounting points and wheel attachment and started moving our components around to find more comfortable places to put everything.

Version 2: 1st Variation Chassis

The first modification of our chassis improved component placement easier and overall made easy assembly of the robot. Nonetheless, there were still a lot of problems that arose when the robot was tested at increased speed levels.

Problem:

On May 24th , 2026, the robot started wobbling, particularly during turns. It was made obvious that the centre of gravity was way too high and the robot was also too front heavy.

Modification:

There was a major redesign of the main chassis where the biggest changes was that the battery was relocated to the back, and we got rid of most of the extra material that just served as extra, unneeded protection to the electrical components.

Wheel Mounting Modification

Problem:
Starting on March 7, 2026, there were repeated cases where the wheels kept becoming loose or falling off when being tested.

Modification:
We further improved upon the wheel mounting system and the securing of wheel hardware.

Result:
There was an immediate improvement in terms of reliability of the wheels during repeated fast-pace testing.

## 3.5 Mechanical Challenges and Lessons Learned

There were several challenges during development that influenced our final mechanical design.

Date | Problem | Impact | Solution / Lesson
03/07/2026 | Wheels falling off | Interrupted testing and affected reliability | Improved wheel mounting and retention
03/29/2026 | 3D prints taking too long | Slowed prototyping | Managed prints between classes
03/01/2026 – 04/19/2026 | Not enough screws | Delayed assembly and repairs | Purchased a screw set
05/05/2026 | BLDC motor becoming loose | Pinion gear lost proper alignment | Tightened and secured motor mounting
05/24/2026 | Robot wobbling during turns | Reduced stability at high speed | Redesigned chassis and moved battery rearward
07/06/2026 | Multiple batteries failed | Prevented normal testing | Replaced batteries and changed supplier
07/27/2026 | Robot turned into walls in difficult cases | Robot could fail to recover from certain obstacle approaches | Continued testing and adjusted navigation/steering behaviour
08/09/2026 | Raspberry Pi failure | Stopped software development | Replaced/repaired computer and recovered development
08/09/2026 | Regulator short circuit | Electrical system became unsafe/non-functional | Rewired and re-soldered connections

These such issues have shown us that mechanical design is not only about creating a robot that will work one time. The robot should be reliable after all drives, tests, adjustments and repairs. Issues such as loose wheels, movement of motors, and improper weight distribution could be discovered only during testing because they were not visible at the initial stage of the design.

Thus, the final mechanical design is the outcome of a repeated sequence of steps: design -> build -> test -> discover problems -> modify -> re-test.

## 4.1 Wiring & Electrical Architecture

The electrical architecture of the robot is made in a way so that the robot distributes power from the main battery in a safe way to each device with appropriate voltage. This robot is powered by a 11.1V 2200 mAh 3-cell LiPo battery.

The electrical system is separated into two power rails. One rail is for the high-power drive and the other one goes straight to the regulator that, well, regulates the voltage to provide power to the lower-voltage electronics. Having separate lines gives a possibility for the motor to get power straight from the battery without causing damage to devices like Raspberry Pi, camera, LiDAR, and Arduino due to high voltage required for the BLDC motor from the battery.

### Electrical Architecture

The overall electrical architecture of the robot is shown below:

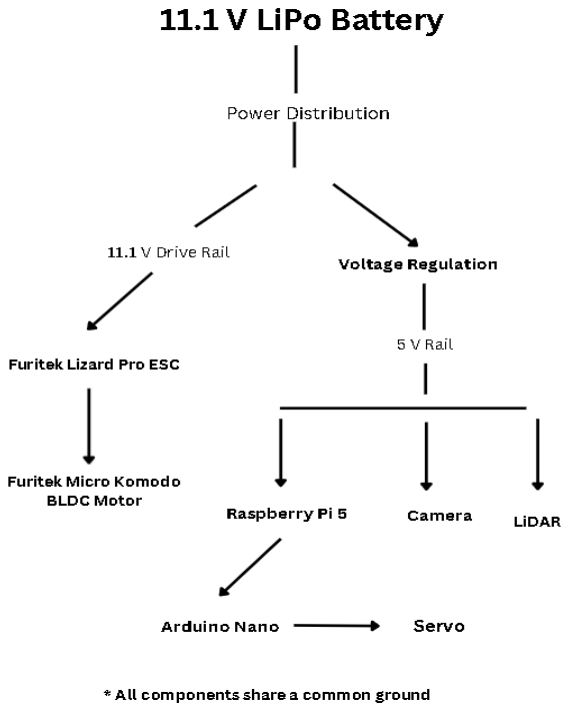
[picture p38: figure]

Figure 2. A hand made diagram of the electrical architecture of our robot.

## 4.2 Power Budget

The robot is powered by an 11.1 V 2200 mAh LiPo battery. In normal operations, the estimated average power consumption is approximately 38 W with an average current consumption of about 3.5 A. However, in situations such as high acceleration or in general high-load conditions, the maximum current drawn from the battery is approximately 15 A.

The drive motor is one of the main sources of power consumption, especially when accelerating. In addition, the Raspberry Pi 5 uses a considerable amount of power in processing the information obtained from the camera and sensors. The camera, LiDAR, Arduino, and the steering system contribute small proportions to the overall power consumption.

The power budget has been determined using a combination of both the specifications of individual components and the actual current consumption observed during the robot’s operations. This is because neither the motor nor the steering system draw power consistently enough for a set in stone calculation.

### Power Budget Table:

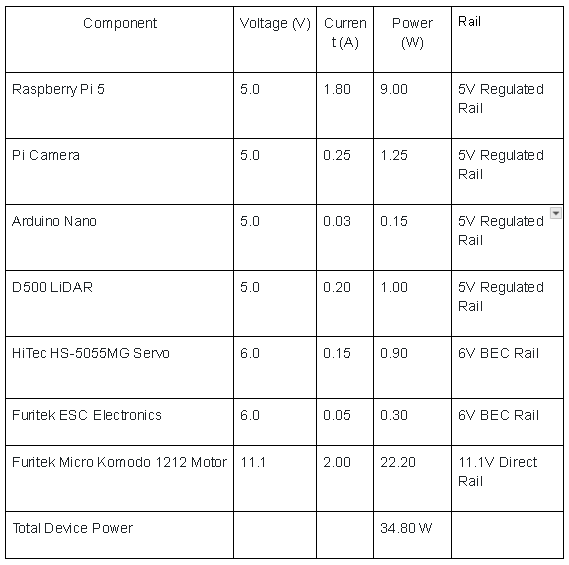
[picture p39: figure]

There are also some minor power losses caused by the voltage regulator when converting the battery voltage to the required regulated 5V. These losses are taken into account while calculating the overall power usage of the robot.

The power system is designed to be capable of supplying the average current load as well as larger currents while accelerating or in other unexpected circumstances.

## 5. Sensors & Perception

The robot uses two main sensors to collect information about the environment and any changes that could come about unexpectedly, as well as making navigation decisions automatically. The two main types of sensors used for perceiving information are Raspberry Pi Camera and D500 LiDAR.

The camera is the by far most important sensor that is being used in the current navigation algorithm, which detects walls, colored pillars, and obstacles around the course.

## 5.1 D500 LiDAR

The D500 LiDAR measures the distance between the robot and the surrounding objects. The LiDAR sensor is placed at the very front of our robot and is oriented in such a way that the front and sides of the robot can be scanned throughout the entire course

### Specifications:

Property | Value
Measurement type | DTOF
Operating range | 0.5m and 2m.
Accuracy | ±20 mm (For ranges between 0.5-2m)
Update rate | 10Hz

LiDAR provides information about the distances of nearby objects or walls. But . The LiDAR does not distinguish colours or shapes of objects. Hence, its practicality differs from the practicality of the camera since it only provides distance information.

## 5.2 Raspberry Pi Camera

The Raspberry Pi Camera is the main perception sensor used by the robot's navigation system. It captures visual data allowing the robot to locate walls and spot red and green poles.

The camera is mounted at a high point on top of a stand at the top of our robot's chassis. and angled at approximately 7° to provide a clear view of the area in front of the robot.

### Specifications:

Property | Value
Resolution | 640 × 480 pixels
Mounting angle | ~7°
Maximum frame rate | 30 FPS

The Raspberry Pi processes each camera frame using computer vision. Different regions of the image are used for wall and pillar detection.

In order to detect walls, the image is converted to the LAB colour space and a Gaussian blur along with morphological filtering are used prior to detecting contours. The two largest valid contours on the left and right sides of the image are used to determine how much wall there is.

In order to detect pillars, the image is converted to the HSV color space and thresholds are used to find red and green pillars while ignoring smaller contours. The position of the pillar is used to determine a steering correction.

The processed data is used by the navigation system to toggle between wall following, pillar avoidance and corner turning.

### Image-Processing Pipeline

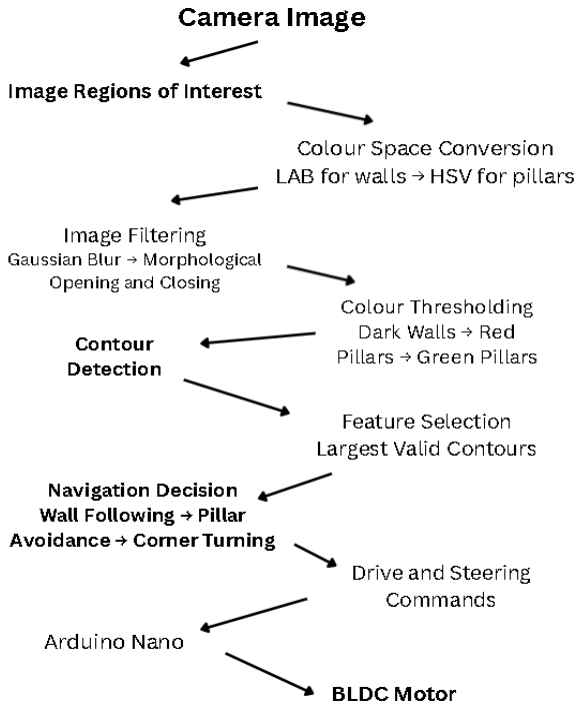
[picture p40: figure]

### Filtering

In order to minimize noise and reduce the number of wrong detections, the imaging system uses several filters. The Gaussian blur filter removes small changes in the picture, whereas morphological opening and closing get rid of noise and close holes in the contours.

When the contours are detected, the algorithm ignores those that are smaller than minimum area thresholds. In addition to this, the navigation system should have the corner detection condition be true for several consecutive frames to enter the corner turning phase.

### Limitations

The camera can be heavily influenced by factors such as lighting, reflection, motion blur, and changes in the colour of objects. Image processing is also considerably more computationally intensive than distance calculations.

## 5.3 Sensor Placement

The sensor placement was made while keeping in mind to make sure both sensors will have a clear view of the environment of the course track and most importantly remain mounted safely.

The camera was placed to give a front view of the track including walls and pillars required by the navigation system. The LiDAR was placed in such a way that it gives distances without any obstruction from the robot’s chassis.

The final positions for the sensors were chosen to maximize useful viewing area and minimize obstructions from other parts of the robot, the part we struggled most with was definitely the camera mount, as there were a multitude of different parts that could go wrong.

## 5.4 Combined Sensor Usage

The camera and LiDAR collect different types of information:
- Raspberry Pi Camera: Detects visual elements like walls and coloured pillars.
- D500 LiDAR: Collects the distance from the objects around.

At the moment, the software is designed in a way that allows using data collected by the camera for autonomous wall following and obstacle avoidance. The LiDAR can provide additional distance information, but is mainly used for parallel parking.

Using more than one sensor gives the robot an opportunity to have different kinds of information about the environment, and creates opportunities to improve consistency and reliability by combining visual and technical distance data.

## 6. Autonomous Driving Algorithm

The autonomous driving algorithm translates sensor data into instructions for the robot’s steering and motors. The Raspberry Pi 5 processes camera images in real time, recognizes key objects in the competition track, and determines the robot’s current driving behavior.

The navigation system can be summarized as this:
1. Camera Input
2. What does the robot see?
Walls, coloured pillars, and changes in the course
3. Feature Detection
Wall detection and pillar detection
4. What should the robot do?
Wall Following → Pillar Avoidance → Corner Turning
5. Calculate Steering and Speed
6. Send Commands to Arduino Nano
7. Control Motor and Steering

## 6.1 Inputs

The main input of the autonomous driving algorithm is the Raspberry Pi camera. The input data from the camera includes images that are processed to then detect:
- Left and right walls
- Red pillars
- Green pillars
- Changes in visible wall area that may indicate a corner

The navigation program also takes into account the state in which it drives. This way, the robot will not try to execute more than one behavior simultaneously.

## 6.2 Processing and Feature Detection

The image captured from the camera is divided into regions of interest for walls and pillars.

In the wall region processing, the robot evaluates the percentage of wall seen by the camera on each side of the screen. The difference between the two sides is calculated and a steering correction then made. Pillars are identified using color thresholds where the program can identify objects that are red and green in color. It identifies their positions on the camera image and uses them to change direction to avoid the obstacle.
It is also able to detect corners through wall detection. To avoid false detection of corners, the robot must maintain multiple framers of the corner before changing its state to the corner-turning one.

## 6.3 Driving States

The robot employs different states for driving based on its detection.
Wall Following:
During regular driving, the robot takes into consideration the information obtained from the wall detection from the left side and the right side of the camera frame. The steering correction is applied in order to ensure that the robot is in a proper position relative to the walls.
Pillar Avoidance:
If the robot detects a red or green pillar that is considered to be a valid "target", it will temporarily switch to the obstacle avoidance mode. Depending on the position and color of the pillar, the robot calculates the direction and value of the steering.
Corner Turning:
In case the robot determines that the corner is approaching, it enters the corner turning state. The corner turn will only be made if the detection condition is stable for several consecutive frames.
Recovery Mode:
After passing a pillar, to get back to normal wall follow the robot uses the last known pillar position and wall measurements to steer back toward a stable driving position before continuing normally.

## 6.4 Outputs

After processing the data captured by the cameras, the Raspberry Pi identifies what outputs need to be sent.

The three main outputs are:
Steering command: Controls the position of the steering servo.
Motor command: Controls the speed at which the robot drives.
Driving state: Indicates whether the robot is in wall tracking, pillar avoidance, or corner turning mode.

These outputs are passed on to the Arduino Nano, which is responsible for low level control of the steering and drive components. The algorithm repeatedly does this while the robot operates, enabling the robot to respond to changes in its environment rather than follow a
pre-programmed set of steps.

## 6.5 Algorithm Design

Our autonomous driving algorithm uses a state based design. The robot does not rely on one form of steering control in all situations. The robot adjusts its behaviour according to the characteristics detected by the camera.

The use of the state-based design ensures that obstacle avoidance and corner turns can become the priority momentarily during the drive rather than the wall following. After completion of the task, the robot can revert back to the normal navigation mode.

The detecting → processing → deciding → controlling cycle is continuously done by the robot to complete the course.

## 7. Control System

The control system takes the navigation system's decisions and translates them into actions by controlling the movements of the servo and dc motor. Although the algorithm for autonomous navigation determines what the robot should do, it is the control system that decides how to do it.

The control system can be summarized as:
1. Navigation Decision
2. Calculate Steering and Motor Command
3. Send Command to Arduino Nano
4. Control Steering Servo and Drivy System
5. Robot Movement

## 7.1 Steering Control

The Raspberry Pi determines a steering correction using the information captured by the camera. In wall following, the difference between the left and right wall areas gives the direction in which the robot should turn either left or right.

During pillar avoidance and corner turning, the steering commands are determined according to the driving state of the robot.

The last stage involves sending the steering command to the Arduino Nano to control the steering servo.

The steering system was calibrated by setting different commands for the servo while comparing them to the physical orientation of the front wheels. The centre command was set according to the physical straightness of the wheels and not just the theoretical centre value.

## 7.2 Motor and Speed Control

The Arduino Nano also gets the driving commands from the Raspberry Pi and manages the Furitek Lizard Pro ESC and Micro Komodo motor.

The motor speed is chosen depending on the navigation behavior at the moment. The robot can apply various driving commands when navigating, avoiding obstacles, and turning corners.

This motor management system provides an opportunity for the autonomous algorithm to slow down the movement of the robot if another behavior of driving is required.

## 7.3 Feedback and Control Accuracy

The existing control system relies mostly on data from the camera in terms of feedback related to the robot's positioning relative to the surroundings.
For instance, after applying a steering correction, the new camera frames contain new information about the detected walls and obstacles and, thus, a new correction needs to be calculated, if required.

This creates a continuous control process:
Detect Environment → Calculate Error → Adjust Steering → Move → Detect Environment Again

## 7.4 Calibration

Calibration was essential for making sure the commands from software created the intended motion.

Tests for the steering servo were done to determine:
- The physical centre position
- Maximum safe left position
- Maximum safe right position

These values were used in the software so that all steering commands fall within the mechanical limits of the robot.
Also, motor commands were tested for suitable speeds in driving conditions. Faster speeds meant quicker completion of the course but made steering less reliable and obstacle avoidance tough.

## 7.5 Calculations Vs. Reality

Most of the calculations we had for the values of the servo commands differed immensely to the real life, final values. For the servo it ranges 0-180°, and 500-2500μs for the standard version, meanwhile the BLDC motor’s final values didn’t change at all to the calculated values, the BLDC motor’s standard ESC Pulse-Width ranges from 1000-2000μs.

### Servo

The servo controls the degree of rotation for our wheels with a rotation of the shaft, this shaft is usually able to reach 0-180° resulting in a midpoint of 90° or 1500μs. With the position the servo is on our robot the midpoint is shifted to 82° or 1411μs. The old midpoint was 66° as the servo’s code was redesigned in some changes. The formula to find the Pulse Width μs from degrees is listed below. We used this formula in our calculations for the midpoint where theta is the midpoint degrees we were using. I.e 90°

Figure 3. A screenshot depicting the formula to find Pulse Width μs from degrees.

Below is a table of all the conversions we did which includes our midpoints, as well as the real and theoretical max left and right angles.

Angle (θ) | Pulse Width (500–2500 μs Standard) | Pulse Width (1000–2000 μs Alternate)
0° (Max left theoretical) | 500μs | 1000μs
42° (Max left real) | 967μs | 1233μs
66° (Old Center) | 1233μs | 1367μs
82° (New Center) | 1411μs | 1456μs
90° (Theoretical midpoint) | 1500μs | 1500μs
122° (Max right real) | 1856μs | 1678μs
180° (Max right theoretical) | 2500μs | 2000μs

Below is a table of our calibrations:
Test | Result | Final value
Steering Centre | Wheels Physically Straight | 82° or 1411μs
Maximum Left | Safe steering limit | 42° or 967μs
Maximum Right | Safe steering limit | 122° or 1856μs
Driving Speed | Stable navigation | 1622μs

## 8. Obstacle Avoidance Strategy

The robot uses the Raspberry Pi Camera for detection and recognition of the obstacle and its location within the course. Based on the Raspberry Pi processing of the camera's image, the decision of which way to move in order to avoid the obstacle is made.

### 1. Detection

The camera takes continuous pictures of the circuit. Using computer vision, obstacles can be detected in the robot's path.

### 2. Classification

It is decided where the obstacle is located with respect to the robot – whether left, centre or right. In addition, using the camera, course colours are identified.

### 3. Decision

The robot determines which direction it should move around the obstacle in.

### 4. Avoidance

While making its way around the obstacle, the robot constantly processes camera pictures.

### 5. Recovery

Once the obstacle is bypassed, the robot returns to its normal driving path and continues to follow the navigation algorithm.

### Flow Chart

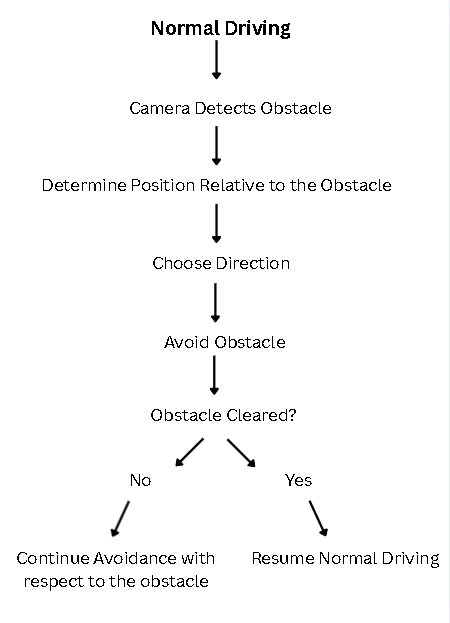
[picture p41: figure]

## 9. Parking Strategy

Parking was considered in the design process but was less of a priority when compared to the main driving and obstacle-avoidance strategy. The parking area is detected using the D500 LiDAR and also helps with determining the position of the robot when parking.

Parking Procedure:
1. Approach – The robot approaches the parking area slowly.
2. Detection – The D500 LiDAR detects the area and assists in identifying the parking spot.
3. Alignment – The robot aligns itself to the parking area.
4. Slow Down – The robot reduces its speed.
5. Park – The robot follows the steering procedure to park in the parking area.

### Parking Flowchart

Approach Parking Area
↓
Detect with LiDAR
↓

Align
↓
Reduce Speed
↓
Enter Parking
↓
Stop

## 10. Testing & Experiments

Experimentation was critical in designing the robot. Repeated tests were carried out by our team in order to refine the performance of the robot in terms of steering, wall-following, vision processing, avoiding obstacles, making turns, and movement speed.

The main idea behind each experimentation process was modifying a single variable while monitoring its effects on the robot. Based on the outcome, the modification would either be accepted, changed, or undone.

## 10.1 Experimentation Log

Test | Variable | Result | Conclusion
1 | Steering angle / servo midpoint | The initial midpoint value for the servos was set at 66°. However, after testing the robot's turning ability and its behavior, the new midpoint was set to 82°. | 82° provided a more reliable and consistent steering centre, so it was used in the final system.
2 | Wall distance / wall-following measurement | Many experiments were conducted on the walls of the left and right sides of the camera to understand the impact of the robot’s position on the wall areas. | Measuring the ratio between the left and right wall lengths helped in deciding whether the robot had moved too much to either direction.
3 | PID Kp and Kd values | Various values of P and D gains have been tried out for finding an optimum | Using P and D control provided sufficient steering correction while

| | point between the two. The values obtained were Kp = 30 and Kd = -2.5. | avoiding unnecessary integral accumulation.
4 | Camera colour space and thresholding | Different types of thresholding were used, such as RGB, HSV, and CIELAB/LAB. The thresholds were repeatedly modified to optimize wall and obstacle detection at various lightings. | LAB space was chosen to detect walls since it offered a better distinction between the darker walls and their surroundings. The use of HSV space was maintained to detect the pillars with colors.
5 | Driving speed | The recommended motor speed was tested first, followed by additional testing using estimated motor command values between approximately 1500–1750 μs. | 1622 μs was selected because it provided a good balance between driving speed and the robot's ability to make reliable steering corrections.
6 | Camera ROI size and placement | The camera regions of interest (ROIs) were continuously modified during development. Modifications of the chassis and even slight modifications of the camera placement necessitated re-calibration of the ROIs. | The chosen ROIs offered relevant wall information without having too much image processing involved. ROI positioning is a part of the calibration of the camera itself.
7 | Corner-turn angle | Different steering angles were tested for left and right corner turns. The final values were 42° for left turns and 122° for right turns. | Fixed steering angles provided a simple and repeatable way to handle corners without requiring the gyro-based turning system.

8 | Obstacle detection | Different color threshold values and contour detection filters were experimented with to distinguish the red and green columns without any false detections. | Combining color threshold with checking for contour size, aspect ratio, position and solidity helped achieve better and more reliable obstacle detection.
9 | Pillar avoidance steering | The target positions for the detected pillars were tuned separately. The final target positions were x = 90 for red and x = 550 for green. | The distinct targets enabled the robot to navigate towards the right direction while avoiding each pillar.

## 10.2 Steering Angles

Objective:
To find the steering angles at which the robot can take successful left and right turns without oversteering.
Hypothesis:
As the steering angles are increased, the robot should be able to take sharper turns, but it may overshoot the desired route.
Method:
Testing with various servo angles while the robot is moving through corners and measuring how well the robot stays on the desired track.
Results:
Many tests were done, and the steering angles were fine-tuned till the robot was successfully able to take the turns.

Conclusion:
Using fixed steering angles worked better than varying the steering angle while taking the turn.
Action:
The current code uses:
- Left turn: 42°
- Right turn: 122°
- Centre: 82°

## 10.3 Wall-Follow Distance

Objective:
Finding out what is the most reliable distance to keep from the wall when following it. Hypothesis:
If the robot follows the wall keeping its distance, its movement will be more smooth and there will be no need for steering corrections.
Method:
Test the robot on the track by moving it at various distances from the wall.
Results:
To check how far the robot was from the wall, the difference between the areas visible from the left and right parts of the camera was found out.
Conclusion:
Comparison of the two camera areas proved to be a good way to adjust the robot's distance to the wall.
Action:
Now the robot computes the error according to the left and right wall areas.

## 10.4 PID Kp

Objective:
Find out what proportional gain is appropriate for following walls.
Hypothesis:
Raising Kp would make the robot react more to error, but high Kp causes oscillation. Method:
Change the Kp while the robot moves on straight parts and around corners. Results:
Low Kp values led to slow correction, and high Kp values gave a strong reaction from the steering.
Conclusion:
A moderate Kp value struck a good balance.
Action:

The current value is: 30

## 10.5 PID Kd

Objective:
To see whether derivative control would improve the stability of wall following. Hypothesis:
Derivative control will dampen rapid movements in the steering.
Method:
Various Kd values were tested through the observation of the robot's movements. Results:
Various values were tested to see the amount of damping needed.
Conclusion:
A little amount of derivative control was needed to dampen steering changes. Action:
The current value is: -2.5

## 10.6 Camera Threshold

Objective:
Determine robust colour thresholds to detect the course walls and coloured pillars. Hypothesis:
A change in the colour thresholds would help detect the object and minimize false detection due to illumination.
Method:
Apply different LAB and HSV thresholds in different illuminations.

Results:
Detection of dark walls using LAB colour space and red and green pillars using HSV colour space was successful through the camera.
Conclusion:
The use of different colour spaces to perform different operations was successful. Action:
The current code has used LAB to detect the walls and HSV to detect the red and green pillars.

## 10.7 Driving Speed

Objective:
Find the driving speed that will make the robot finish the course fast while still being able to control it effectively.

Hypothesis:
Higher speeds will lead to reduced run time; however, controlling and avoiding obstacles will become increasingly difficult.
Method:
Try different values for the motors on straight paths, corners, and obstacle paths. Results:
Increased speed made it harder to control the path and avoid obstacles. Conclusion:
Moderate speed gave a better combination of speed and reliability. Action:
Current normal driving speed is: 1622

## 10.8 Pillar Detection

Objective:
Enhance the robot’s performance in identifying coloured pillars
Hypothesis:
Applying size, height, aspect ratio, and solidity filters to the detected contours will improve pillar detection accuracy.
Method:
Apply the filter settings to the camera for various shapes and sizes.
Results:
The detection process discards any object that is small, too short, too wide, or not regular.
Conclusion:
Using a combination of geometric filters helps to increase the accuracy of pillar detection.
Action:
The existing program includes filters for the minimum area, height, aspect ratio, and width.

## 10.9 Avoiding the Pillar

Objective:
To see if the robot can turn away from a detected red or green pillar.
Hypothesis
It will be possible for the robot to adjust its steering by determining the position of the pillar horizontally in the camera image.
Method:
Place the red and green pillars in different positions and record their responses. Results:

The robot finds the difference between the center of the pillar that is detected and the target position.
Conclusion:
It is possible for the robot to adjust its steering according to the position of the pillar. Action:
The current code uses different target positions:
RED_TARGET_CX = 90
GREEN_TARGET_CX = 550

## 10.10 Testing Process

Testing followed an iterative process:

1. Design
2. Build / Program
3. Test
4. Record Results
5. Identify Problem
6. Change One Variable
7. Retest
8. Keep or Reject Change

This process allowed the team to make changes based on measured performance rather than assumptions.

Testing Philosophy

The main goal of testing was reliability before speed. A change was only considered an improvement if it made the robot more consistent without creating new problems anywhere else on the course.

## 11. Design Iterations

The robot was developed through several iterations. Each major change was made in response to problems we found during testing.

## 11.1 Iteration Timeline

1. Initial Prototype

2. Steering Testing
3. Servo midpoint changed: 66° → 82°
4. Control System Tuning
5. P and D values adjusted; I term removed
6. Vision Testing
7. LAB selected for wall detection
8. Camera / Chassis Adjustments
9. ROIs recalibrated
10.Speed and Obstacle Testing
11. Final Robot

## 11.2 Major Design Iterations

### Iteration 1 – Steering Calibration

Date: 2026-09-01
- What changed: Changed the steering midpoint from 66° to 82°.
- Why: The initial midpoint failed to provide reliable straight line steering.
- Test result: The robot drove straighter.
- Pros: Improved straight line driving and steering.
- Cons: Needed to calibrate other steering values around the new midpoint.

### Iteration 2 – Control System

Date: 2026-02-08-2026-07-16
- What changed: Tried several P and D values and received Kp = 30, Kd = -2.5. The I term was not used.
- Why: Need to tune the control system.
- Test result: P and D control was enough to correct the flat course.
- Pros: Better control when following walls.
- Cons: Much time spent on testing and tuning.

### Iteration 3 – Vision System

Date: 2026-05-10
- What changed: Tested RGB, HSV and LAB. Lab colour space chosen for wall detection and HSV for coloured pillars.
- Why: Different colour spaces gave different results.
- Test result: LAB colour space worked better for wall detection in our environment.

- Pros: Better differentiation between walls and the background.
- Cons: Miss out on the ease of use with RGB

### Iteration 4 - Camera and ROI placement

Date: 2026-03-31, 2026-04-12, 2026-04-18, 2026-05-03, 2026-06-21, 2026-06-25
- What changed: The ROIs of the camera were changed multiple times.
- Why: Changing the chassis or camera placement affected its field of vision.
- Test result: New ROIs helped improve wall detection.
- Pro: Improved focus of image processing.
- Con: Mechanical changes required new software adjustments.

### Iteration 5 - Speed of driving

Date: 2026-07-25
What changed: Motor values from approximately 1500-1750 μs were tested.
Why: There needed to be a compromise between speed and proper steering & image processing.
Test result: 1622 μs was the value providing the best results.
Pro: Increased reliability without reducing speed.
Con: Higher speed may decrease reaction time.

*Date uses a year/month/day format*

## 11.3 Final Robot Design

The final robot incorporates all the improvements found during testing such as 82° steering center point, P & D tuned control, camera colour processing, calibrated ROIs, and a BLDC motor PWM of 1622 μs.

## 12. Problems & Solutions

Problem | Investigation | Cause | Solution and Result

Unexpected startup movement | Checked the Arduino reset, startup delay, and initial motor commands. | The Raspberry Pi and Arduino did not always initialize at the same time. | Added a startup delay and controlled motor initialization, making startup more predictable.
Unreliable camera detection | Tested RGB, HSV, LAB, and different threshold values. | Lighting and colour variation affected detection. | Used LAB for wall detection and HSV for coloured pillars, improving detection reliability.
Camera ROIs became inaccurate | Checked the camera view after chassis or camera-position changes. | The ROIs depended on the camera's physical position and angle. | Recalibrated the ROIs after mechanical changes and kept the final camera position consistent.
Unreliable obstacle detection | Tested colour thresholds and contour filtering. | Colour alone could detect noise or invalid objects. | Added filters for area, size, position, aspect ratio, and solidity, making pillar detection more selective.
Driving speed affected control | Tested motor commands between approximately 1500–1750 μs. | Higher speeds reduced the time available for camera processing and steering corrections. | Selected 1622 μs, providing a better balance between speed and reliable control.

## 13. Performance Analysis

The final robot was assessed through the criteria of speed, accuracy, reliability, and power consumption. These criteria helped determine if the changes made to the design were effective.

## 13.1 Performance Summary

Category | Measurement | Result
Speed | Maximum speed | 32.23 m/s
Speed | Average speed | 4.1 – 6.8 m/s
Accuracy | Steering error | ~15%
Accuracy | Wall distance error | ~8/10
Accuracy | Obstacle detection accuracy | ~8/10
Reliability | Successful runs | 9/10
Reliability | Failed runs | 1/10
Reliability | Collision rate | 1/10
Power | Average current | Approximately 3.5 A
Power | Peak current | Approximately 15 A
Power | Battery runtime | Approximately 40–60 minutes

## 13.2 Performance Comparison

Robot Version | Best Time | Successful Runs | Main Improvement
Initial Prototype | 2:46 | 2/10 | Baseline performance
Steering-Calibrated | 2:12 | 5/10 | Improved steering consistency
Control and vision | 1:57 | 7/10 | More stable wall following and detection
Final | 1:37 | 9/10 | Combined mechanical and software improvements

*open challenge times*

## 13.3 Analysis

The final robot's performance should be compared with the previous robots to see whether design changes improved its reliability and controllability. The key criteria are accurate steering, obstacle detection, number of successful runs, and completion time.

The robot's power system consists of a battery with an average current of about 3.5 A, peak current of about 15 A, and battery operation time of 40–60 minutes.

## 13.4 Evidence

The performance evidence was collected and will be collected moving forward from:

- Timed driving trials.
- Successful and failed run records.
- Collision records.
- Camera detection results.
- Steering and wall-following observations.
- Battery and current measurements.
- Competition results and performance videos.

## 14. Final Robot

The final robot uses all the changes made to the mechanical, electrical, and programming aspects throughout the process of designing. The completed design will be able to navigate through the course autonomously, detect walls, obstacles, and manoeuvre as required in the competition.

## 14.1 Final Robot Views

The photos below show the completed robot from all the major views possible. Components and important features are labelled for identification.
View | Image | View | Image

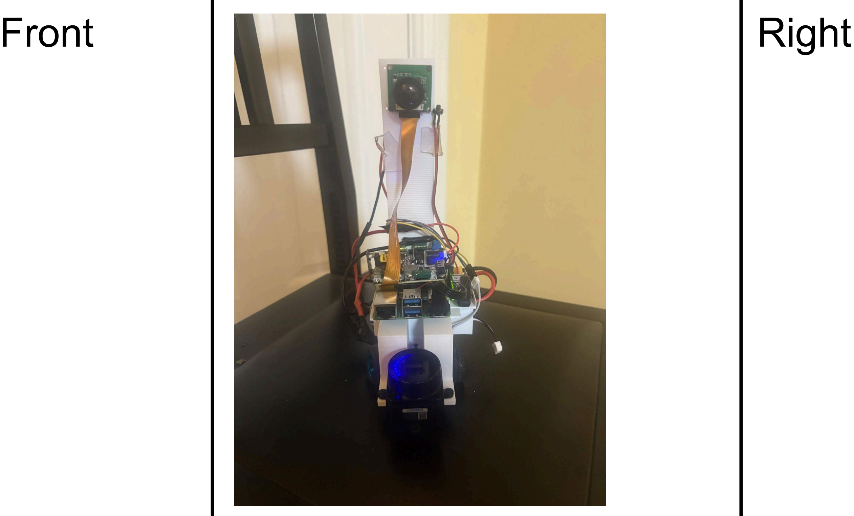
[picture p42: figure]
Front; Right
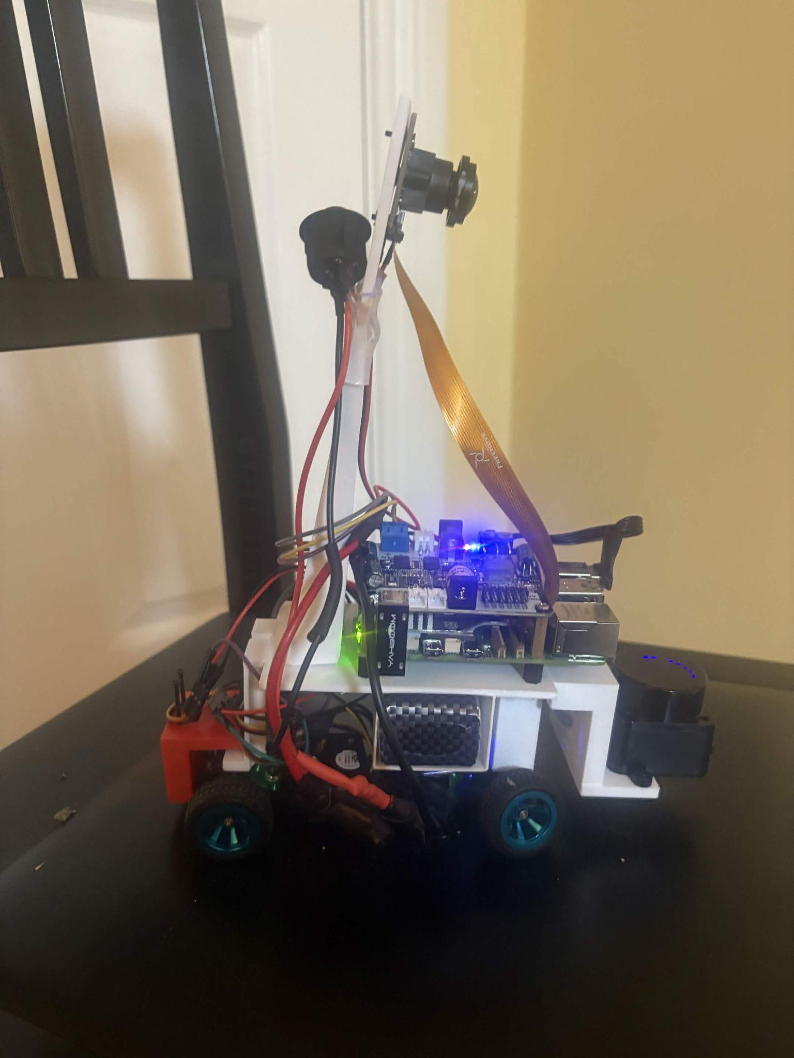
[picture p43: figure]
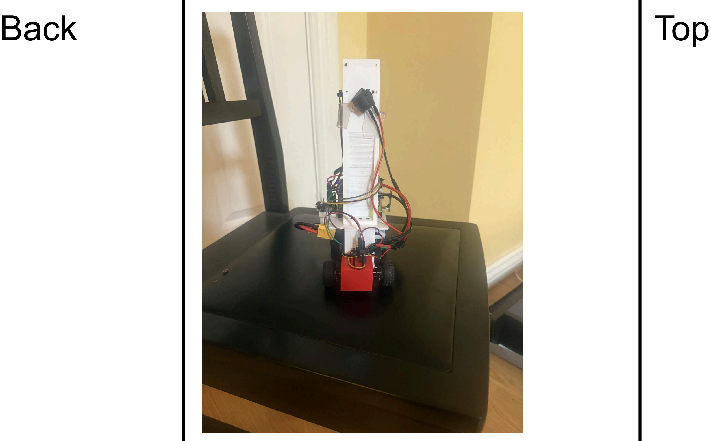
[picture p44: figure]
Back; Top
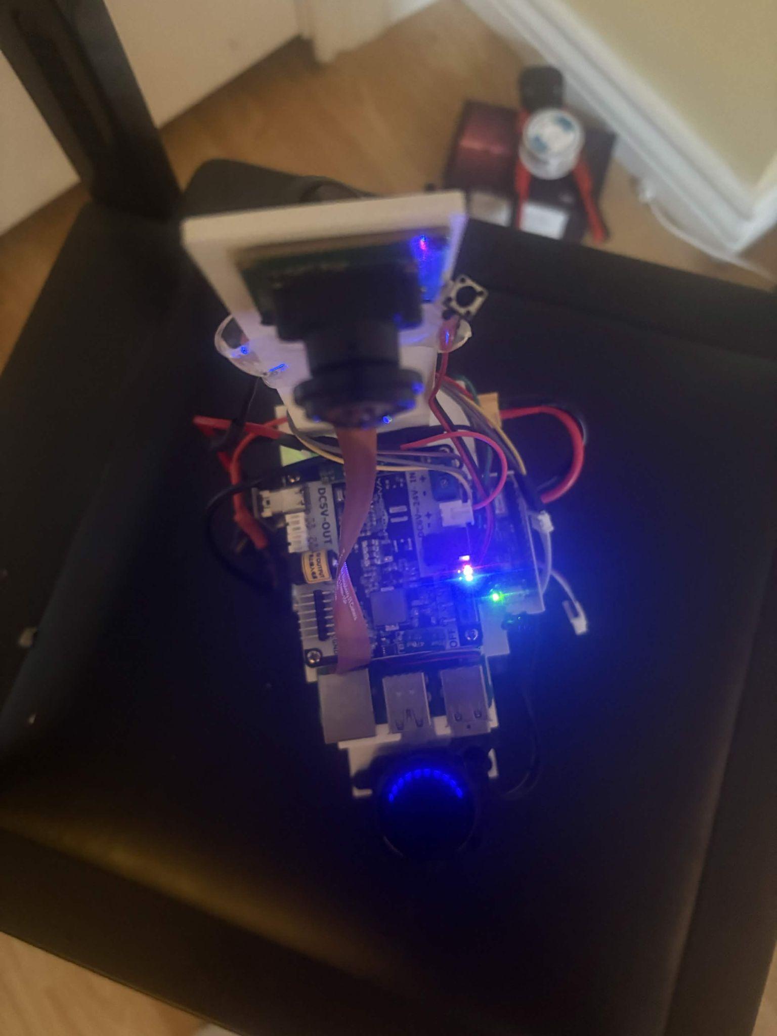
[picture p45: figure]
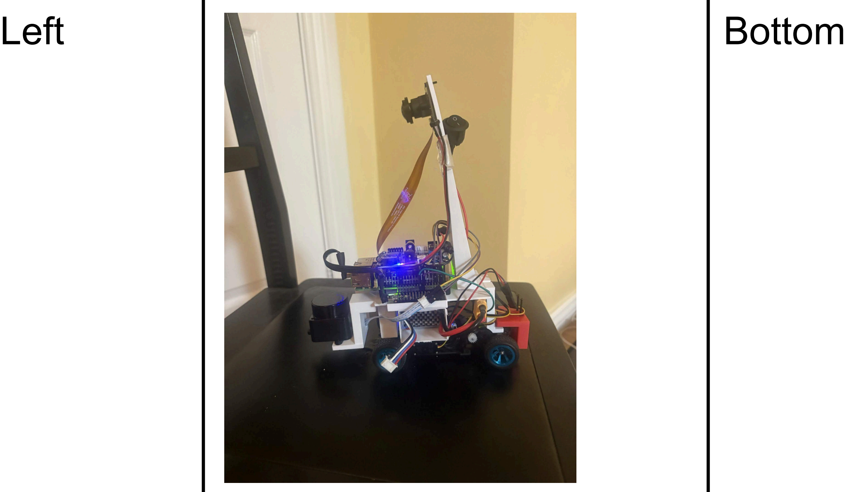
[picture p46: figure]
Left; Bottom
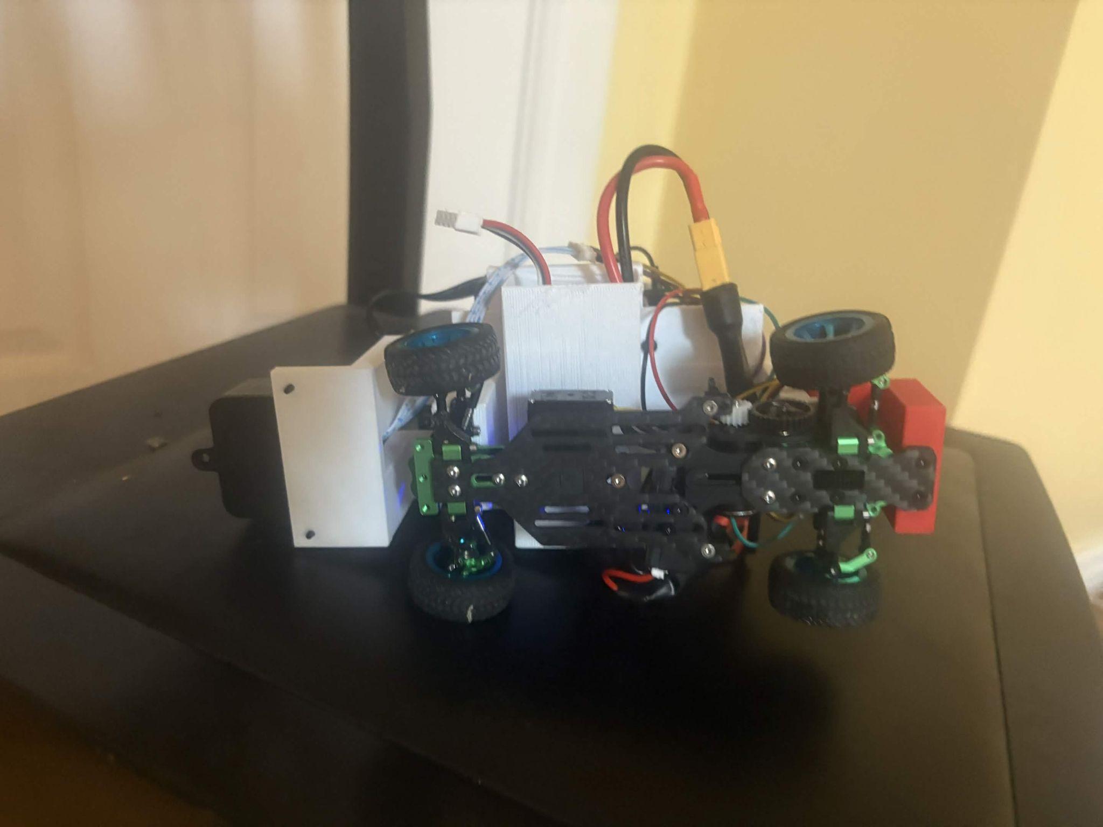
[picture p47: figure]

## 14.2 Final Specifications

Specification | Final Value
Computer | Raspberry Pi 5
Controller | Arduino Nano
LiDAR | D500
Camera | Raspberry Pi Camera
Motor | Furitek Micro Komodo 1212
ESC | Furitek Lizard Pro
Steering | Servo motor
Battery | 11.1 V 2200 mAh 3S LiPo
Average power | ~38 W
Average current | ~3.5 A
Peak current | ~15 A
Weight | 567g
Dimensions | Length: 21cm, Width: 10cm, Height: 23.5cm
Maximum speed | 32.23 m/s

## 14.3 Final System

The Raspberry Pi 5 conducts the primary computer vision and decision-making functions. The Arduino Nano executes the lower-level operations such as steering and control of the motors. The camera gives the vision data for wall and obstacles detection, and the D500 LiDAR is used for the parking system.

This is the final robot which reflects the outcome of the work carried out during the mechanical, electrical, and programming developments described in the engineering journal.

## 15. Reproducibility

The robot was documented such that another team would be able to replicate the design based on the documents contained in this repository. All the major mechanical, electrical, and software systems have been documented along with their respective configurations and calibrations.

## 15.1 Parts

Component | Manufacturer | Model
Computer | Raspberry Pi | Raspberry Pi 5
Microcontroller | Arduino | Arduino Nano
Camera | Raspberry Pi | Raspberry Pi Camera
LiDAR | LDROBOT | D500
Motor | Furitek | Micro Komodo 1212
ESC | Furitek | Lizard Pro
Servo | HiTEC | HS-5055MG Metal Gear Digital Micro Servo
Battery | Zeee | 3S 11.1 V 2200 mAh LiPo
*Complete component specifications and additional parts are documented in the repository.*

## 15.2 Mechanical Construction

The mechanical design is documented using:

- CAD files
- Dimensioned drawings
- 3D-print files
- Component measurements
- Assembly photographs

All the CAD files, 3D-print files, and mechanical drawings can be found on our github.

## 15.3 Electronics

The electrical system is documented using a complete wiring diagram and component connections.

Documentation includes:

- Wiring diagram
- Raspberry Pi connections
- Arduino pinout
- Sensor connections
- Motor and ESC connections
- Power distribution
- Voltage regulation

Circuit diagram:

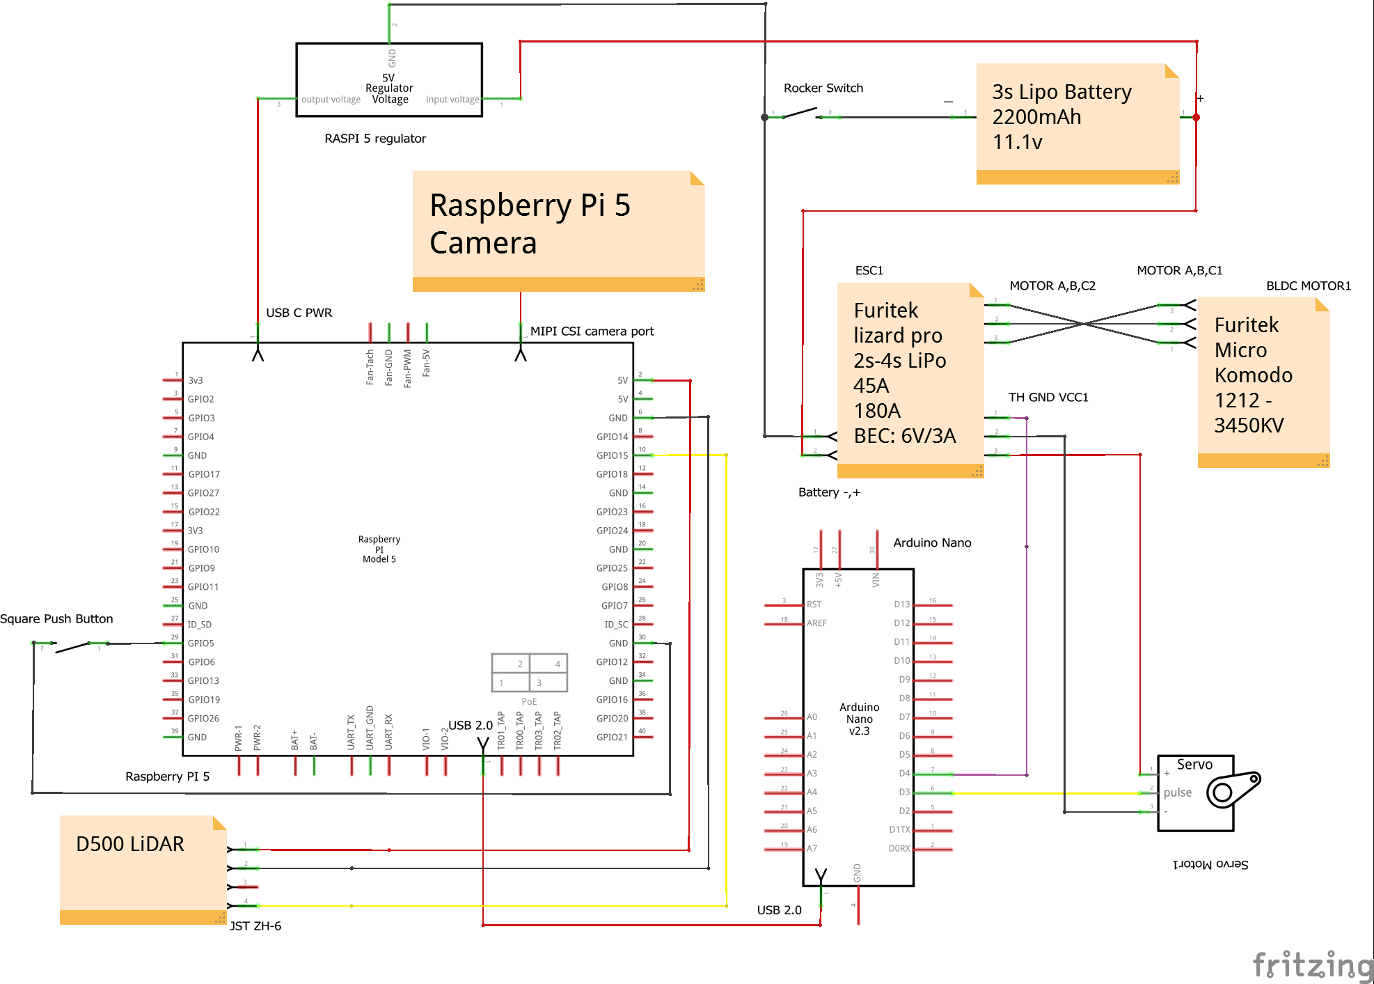
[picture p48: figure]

## 15.4 Software

The complete software is available in the repository.

Requirements

- Raspberry Pi 5
- Python 3
- OpenCV
- NumPy
- Picamera2
- Serial communication libraries
- GPIO libraries

Configuration

The software requires configuration of:

- Camera settings and ROIs
- LAB and HSV thresholds
- Steering centre
- Motor values
- PID parameters
- Obstacle-detection parameters

The final configuration values are documented alongside the source code which can be found on our github as well, in the designated “Code” folder.

## 15.5 Calibration

Before operating the robot, the following systems must be calibrated:

1. Steering: Set the servo centre and verify that the wheels point straight.
2. Motor: Determine the neutral value and gradually increase the motor command until the desired driving speed is reached.
3. Camera: Position the camera consistently and adjust the ROIs and colour thresholds.
4. LiDAR: Verify distance readings at known distances and confirm the sensor's orientation.
5. Sensors: Check that all sensor readings are received correctly by the Raspberry Pi and Arduino.

## 15.6 Assembly Order

The recommended assembly order is:

1. Assemble the chassis.
2. Install the motor, wheels, and steering system.
3. Mount the Raspberry Pi, Arduino, ESC, and battery.
4. Install the camera and LiDAR.
5. Complete the electrical wiring and voltage regulation.
6. Upload and configure the software.
7. Calibrate the steering and motor.
8. Calibrate the camera and sensors.
9. Test each subsystem individually. 10.Perform complete autonomous testing.

## 15.7 Reproducibility Resources

The repository contains the files required to recreate the robot, including:

- CAD and mechanical files
- Electrical schematic
- Source code
- 3D-print files
- Component specifications
- Calibration values
- Assembly photographs
- Testing and configuration information

This is the link to our GitHub: https://github.com/JBH1229/WRO-2026-FE

## 15.8 Calibration Values Table:

## 16. GitHub / Code

The GitHub repo contains the source code for the robot, the engineering documentations, the electrical schematics, and other files. This repository allows for access to the development history as well as the final product.

## 16.1 Repository Contents

The main sections of the repository contain:

Section | Contents
Engineering Journal | Documentation of the robot's development and testing
Software | Python and Arduino source code
Electrical | Circuit diagrams, wiring, and electrical documentation
Mechanical | CAD files, designs, and mechanical documentation
Images | Robot photographs, diagrams, and testing images
Setting | Final Value
Steering centre | 82°
Motor neutral | 1500 μs
Driving speed | 1622 μs
Kp | 30
Kd | -2.5
Camera resolution | 640 × 480
Red target X | 90
Green target X | 550

## 16.2 Software

The robot's software is divided between the Raspberry Pi 5 and Arduino Nano.

### Raspberry Pi

The Raspberry Pi runs the main program and is responsible for:
- Camera Processing
- Wall detection
- Obstacle detection
- Navigation decisions
- LiDAR communication
- IMU monitoring
- Sending motor and steering commands

### Arduino Nano

The Arduino handles the lower-level hardware control, including:
- Steering servo commands
- Motor commands
- IMU communication
- Communication with the Raspberry Pi

## 16.3 How the Software Works

The main autonomous program can be shown through a state-machine diagram structure.
1. Wall Following
2. Corner Detected
3. Corner Turn
4. Wall Following
5. Pillar Detected
6. Pillar Avoidance
7. Recovery
8. Wall Following
The Raspberry Pi constantly processes information from the camera and decides which main state the robot is in. After that, the steering and motor control commands are sent to the Arduino.

## 16.4 Installation and Running

The software requires a Raspberry Pi 5 with the required Python libraries and connected hardware.

Basic setup:

1. Clone or download the repository.
2. Install the required Python dependencies.
3. Connect the Raspberry Pi to the Arduino and sensors.
4. Verify the correct serial ports.
5. Check the camera and sensor connections.
6. Apply the documented calibration values.
7. Run the main autonomous program.

Make sure to calibrate the steering, motor speed, kp & kd, and the red & green pillars before running.

## 16.6 Version History

The commit history on GitHub records the evolution of the robot and also allows the previous versions of code and documentation to be viewed. This provides evidence towards the evolution of the software through the entire engineering process.
Therefore, the repository can act as both a code archive and development record, as it shows how the final robot was produced throughout all the variations in software and hardware.

## 17. Engineering Goals

At the start of the project, we defined engineering objectives to assess the performance and reliability of the robot. These engineering objectives were used to determine if our final design lived up to our initial expectations.

Goal | Target | Final | Achieved?
Speed | <2:30 | 1:37 | ✅
Wall follow & pillar error | >80% | ~80% | ✅
Runtime | >2h | ~40-60m | ❌
Successful runs | >80% | ~90% | ✅

## 18. Future Improvements

While the final robot successfully combines autonomous drive, wall following, obstacle avoidance, and sensing navigation together effectively, there are still some improvements that can be made to the robot in a future iteration. Each improvement is clear-cut and will be testable based on performance measurements.

## 18.1 Mechanical

- Decrease weight: Modify the chassis design and strip out unnecessary components to decrease the total weight of the robot.
- Enhance steering geometry: Optimize the steering mechanism design to decrease steering slack and increase consistency between the servo and wheel positions.
- Improve chassis stiffness: Make stronger sections of the chassis that flex when the robot is moving to ensure the camera and steering geometry stay consistent.
- Enhance wheel traction: Experiment with different wheel designs to come up with one that increases traction without decreasing roll resistance.

## 18.2 Electronics

- Increase power regulation efficiency: Use an improved voltage regulator for minimizing variations in voltage and ensuring better power supply to the Raspberry Pi and sensors.
- Increase cable routing effectiveness: Increase the quality of cable routing and soldering to minimize chances of improper cable connections.
- Minimize electrical noise: Organize power supply of the motor system and other cables in such a way as to minimize interference of electrical nature.
- Improve sensors mounting reliability: Mount sensors in such a way that they don’t move during collisions or trials.

## 18.3 Sensors

- Enhance camera calibration: Implement a more systematic procedure of calibrating cameras such that thresholds and regions of interest are consistent regardless of varying lighting situations.
- Improve LiDAR filtering: Incorporate further filtering in order to eliminate unreliable or noisy LiDAR data before they are used by the robot.
- Implement improved sensor fusion: Combine information from the camera, LiDAR, and IMU whenever appropriate to aid navigation.

## 18.4 Software

- Obstacle detection improvement: Refine colour thresholding and contour filtering techniques further in order to avoid incorrect detections and provide consistent obstacle detections.
- Control algorithm improvement: Try out some more advanced control strategies in order to decrease the robot's oscillations while driving and provide more consistent distance from the wall.
- Latency reduction: Improve image processing and sensor processing in order to decrease robot's response time to environment changes.
- Improvement of recovery state: Implement improvements to the recovery state in order to let the robot return to regular wall following mode after recovering from an obstacle or turning a corner.

## 18.5 Strategy

- Enhancement of Obstacle decisions: Look at more methods of obstacle avoidance to see what approach would yield the fastest route.
- Optimization of Driving Path: Modify the target wall position and steer settings to come up with a faster path but ensure reliability of obstacle detection.
- Cornering Enhancement: Experiment with various entry speed and angles of the corner to decrease time used on corners.
- Parking enhancement: Further optimize the parking approach using the LiDAR.

## 18.6 Testing Future Improvements

Future improvements will be tested by comparing the modified robot and the existing one under the same conditions. With respect to each of the changes made, several trials will be done, and various measurable parameters such as lap time, lateral error/wall error, success rate, and collisions will be recorded.

For instance, in testing a better control algorithm, both the present control system and the enhanced one will be run on the same track for ~20 runs. Comparing the two systems will be based on various parameters such as the average wall error, maximum steering error, lap time, and the number of successful runs. The new control algorithm in this example would only be considered an improvement if it produced enough gains without reducing reliability or negatively affecting other parts of the robot

This process would allow future changes to be based on experimental evidence rather than assumptions.

## 19. Links

Link to Github: https://github.com/JBH1229/WRO-2026-FE
Link to Open Challenge video: https://youtu.be/NveL-KeYepw Link to Obstacle Challenge video: https://youtu.be/7QU7L7XVNVw

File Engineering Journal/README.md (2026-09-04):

# This folder contains our engineering journal pdf

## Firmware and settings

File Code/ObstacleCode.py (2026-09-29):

# MAIN ISSUE: PILLAR AVOID LITERALLY JUST WONT END IN GREEN LIGHT RECOVERY MODE BEFORE RECOVERY MODE STARTS
import sys
kickOverride = False
DebugMode = False
AutoStart = True
if len(sys.argv) > 1 and sys.argv[1] == "Debug":
	AutoStart = False
ColorBias = True
PositionRequired = True
ForceDefault = False
DOYELLOW = False
DOEND = False
start_run = False
end_run = False
kick = False
OverrideRed = True
import cv2
import numpy as np
from picamera2 import Picamera2
from time import sleep
import time
import serial
import struct
from gpiozero import Button
#def log(func, *args):
	#def logging_func(*args):
		#print(f"Calling function {func}")
		#func(*args)
	#return logging_func
		
# === Lidar Init ===
PORT = "/dev/ttyAMA0"
BAUD = 230400
PACKET_HEADER = 0x54
PACKET_LEN = 47
read_lidar = True
ser = serial.Serial(PORT, BAUD, timeout=0.1)
buffer = bytearray()
deg_0 = ""
d_0 = [0, None, 0]
deg_45 = ""
d_45 = [45, None, 0]
deg_90 = ""
d_90 = [90, None, 0]
deg_135 = ""
d_135 = [135, None, 0]
deg_180 = ""
d_180 = [180, None, 0]
unread_packets = True
packets_read = 0
max_packets = 5
# LD19 CRC-8 table (standard LDROBOT checksum, poly 0x4D reflected)
CRC_TABLE = [
	0x00, 0x4d, 0x9a, 0xd7, 0x79, 0x34, 0xe3, 0xae, 0xf2, 0xbf, 0x68, 0x25, 0x8b, 0xc6, 0x11, 0x5c,
	0xa9, 0xe4, 0x33, 0x7e, 0xd0, 0x9d, 0x4a, 0x07, 0x5b, 0x16, 0xc1, 0x8c, 0x22, 0x6f, 0xb8, 0xf5,
	0x1f, 0x52, 0x85, 0xc8, 0x66, 0x2b, 0xfc, 0xb1, 0xed, 0xa0, 0x77, 0x3a, 0x94, 0xd9, 0x0e, 0x43,
	0xb6, 0xfb, 0x2c, 0x61, 0xcf, 0x82, 0x55, 0x18, 0x44, 0x09, 0xde, 0x93, 0x3d, 0x70, 0xa7, 0xea,
	0x3e, 0x73, 0xa4, 0xe9, 0x47, 0x0a, 0xdd, 0x90, 0xcc, 0x81, 0x56, 0x1b, 0xb5, 0xf8, 0x2f, 0x62,
	0x97, 0xda, 0x0d, 0x40, 0xee, 0xa3, 0x74, 0x39, 0x65, 0x28, 0xff, 0xb2, 0x1c, 0x51, 0x86, 0xcb,
	0x21, 0x6c, 0xbb, 0xf6, 0x58, 0x15, 0xc2, 0x8f, 0xd3, 0x9e, 0x49, 0x04, 0xaa, 0xe7, 0x30, 0x7d,
	0x88, 0xc5, 0x12, 0x5f, 0xf1, 0xbc, 0x6b, 0x26, 0x7a, 0x37, 0xe0, 0xad, 0x03, 0x4e, 0x99, 0xd4,
	0x7c, 0x31, 0xe6, 0xab, 0x05, 0x48, 0x9f, 0xd2, 0x8e, 0xc3, 0x14, 0x59, 0xf7, 0xba, 0x6d, 0x20,
	0xd5, 0x98, 0x4f, 0x02, 0xac, 0xe1, 0x36, 0x7b, 0x27, 0x6a, 0xbd, 0xf0, 0x5e, 0x13, 0xc4, 0x89,
	0x63, 0x2e, 0xf9, 0xb4, 0x1a, 0x57, 0x80, 0xcd, 0x91, 0xdc, 0x0b, 0x46, 0xe8, 0xa5, 0x72, 0x3f,
	0xca, 0x87, 0x50, 0x1d, 0xb3, 0xfe, 0x29, 0x64, 0x38, 0x75, 0xa2, 0xef, 0x41, 0x0c, 0xdb, 0x96,
	0x42, 0x0f, 0xd8, 0x95, 0x3b, 0x76, 0xa1, 0xec, 0xb0, 0xfd, 0x2a, 0x67, 0xc9, 0x84, 0x53, 0x1e,
	0xeb, 0xa6, 0x71, 0x3c, 0x92, 0xdf, 0x08, 0x45, 0x19, 0x54, 0x83, 0xce, 0x60, 0x2d, 0xfa, 0xb7,
	0x5d, 0x10, 0xc7, 0x8a, 0x24, 0x69, 0xbe, 0xf3, 0xaf, 0xe2, 0x35, 0x78, 0xd6, 0x9b, 0x4c, 0x01,
	0xf4, 0xb9, 0x6e, 0x23, 0x8d, 0xc0, 0x17, 0x5a, 0x06, 0x4b, 0x9c, 0xd1, 0x7f, 0x32, 0xe5, 0xa8,
]
def calc_crc8(data):
	crc = 0
	for b in data:
		crc = CRC_TABLE[(crc ^ b) & 0xFF]
	return crc
def find_packet_start(buffer):
	for i in range(len(buffer) - 1):
		if buffer[i] == 0x54 and (buffer[i+1] & 0xFF) == 0x2C:
			return i
	return -1
def parse_packet(packet):
	if len(packet) != PACKET_LEN:
		return None
	if calc_crc8(packet[:46]) != packet[46]:
		return None
	speed = struct.unpack_from('<H', packet, 2)[0] / 64.0
	start_angle = struct.unpack_from('<H', packet, 4)[0] / 100.0
	measurements = []
	for i in range(12):
		offset = 6 + i * 3
		dist = struct.unpack_from('<H', packet, offset)[0]
		confidence = packet[offset + 2]
		measurements.append((dist, confidence))
	end_angle = struct.unpack_from('<H', packet, 42)[0] / 100.0
	timestamp = struct.unpack_from('<H', packet, 44)[0]
	crc = packet[46]
	return {
		"speed": speed,
		"start_angle": start_angle,
		"end_angle": end_angle,
		"timestamp": timestamp,
		"crc": crc,
		"points": measurements
	}
def interpolate_angles(start, end, count):
	angle_range = (end - start + 360) % 360
	step = angle_range / (count - 1)
	return [(start + i * step) % 360 for i in range(count)]
# --- Arduino init ---
button = Button(5)
arduino = serial.Serial('/dev/ttyACM0', 115200, timeout=1)
arduino.write_timeout = 1.0
# Most Arduinos reset when the port opens; give it time to boot
time.sleep(2.0)
# Clear anything the Arduino might have printed during boot
servo_value = 82
default_servo_value = 82
default_motor_value = 1500
motor_value = 1500
#set default values
arduino.reset_input_buffer()
arduino.reset_output_buffer()
starting = True
turn_side = ""
prev_turn_side = ""
active_cx = 0
active_cy = 0
error_avoid = 0
correction = 0
active_color = None
#IMU Heading Tracking
last_heading_time = time.time()
heading_interval = 0.1 #request heading from arduino every 1 second
imu_heading = 0.0
starting_heading = 0.0
relative_heading = 0.0
first_read = True
end_run_count = False
end_run_counter = 0
END_RUN_LIMIT = 75
TOGGLE_GYRO_TURN = False
GYRO_TURN_VAL = 15
relative_turn_heading = 0.0
abs_turn_heading = 0.0
MIN_NOISE_AREA = 300
MIN_REACT_AREA = 700
MIN_PILLAR_Y = 100
MAX_PILLAR_Y = 250
RED_TARGET_CX = 90
GREEN_TARGET_CX = 570
PILLAR_EXIT_FRAMES = 5
recovery_mode = False
distance_error = 1
offbalance = 0
MAX_OFFREAD = 1000
highest_heading = 0
lap_direction = None # CHANGE BACK TO 'None' AFTER
lap_margin = 30
target_cx = 0
prev_red = False
outer_wall = None
inner_wall = None
pillar_location = None
LIGHT_RECOVERY = 0
NORMAL_RECOVERY = 1
HEAVY_RECOVERY = 2
recovery_type = NORMAL_RECOVERY
start_step = 1
end_step = 1
LEFT = 1
RIGHT = 2
orientation = 0
LED_OFF = 0
LED_RED = 1
LED_GREEN = 2
LED_BLUE = 3
LED_YELLOW = 4
LED_CYAN = 5
LED_MAGENTA = 6
LED_WHITE = 7
#@log
def send_servo(value):
	global servo_value
	value = int(value)
	if value < 0:
		value = 0
	if value > 180:
		value = 180
	valueb = bytes(str(value), encoding="utf-8")
	arduino.write(b"@S%b\n" %valueb)
	servo_value = value
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

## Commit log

2026-02-11 Added to the price table
    fixed up some prices and added a regulator into the price table
2026-03-21 Added our Chassis Model v1.0 3d print design
    [WRO 2026 FE 3D Chassis Model v1.0.stl]
2026-03-29 Update Draft-Code.md
    Added file containing arduino serial receiving code
2026-03-29 added inital PD servo controls for open challange
2026-03-31 Added the ready to print file
    This is for the first rendition of our 3d printed chassis
    [Grand Krunk (3).stl]
2026-03-31 Delete 3d-prints/Grand Krunk (3).stl
    this file was the wrong file
    [Grand Krunk (3).stl]
2026-03-31 Add README for Version 1 of 3D prints
2026-03-31 Added the parts for the 1st version of the chassis
    added the main housing part, the camera stand, the bottom chasis part, and the top half for the battery holder 3d prints.
    [Battery top half.3mf, Camera Stand.3mf, Main housing part.3mf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]
2026-04-09 fixed constent send_motor() and send_servo() sends to arduino to prevent clutter, implemented basic lap tracking system, lowered turning angle for corner turn and exit time for exiting corner turn mo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
2026-04-13 added updated chassis parts
    [bottom chassis v1.2.3mf, camera stand v1.1.3mf, upper chassis v1.2.3mf]
2026-04-19 added the updated camera stand + nano housing
    [Camera stand v1.2.3mf]
2026-04-26 Added arduino housing and front part of the chassis
    [Arduino housing v1.2.3mf, Arduino housing v1.3.3mf, Arduino housing v1.4.3mf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]
2026-05-10 added version 2 file for 3-dprints
    This README file provides information on revised second versions of parts, including the camera.
2026-05-10 added the revised camera stand with screw holes
    [Camera stand v2.3mf]
2026-05-10 changed default servo angle from 75 to 66
2026-05-17 removed write from arduino to pi
2026-06-21 added updated 3d prints
    changed to a date format for version number — easier to read. Added a switch around of the battery to the back and changes to coexist with that.
    [Camera stand 6.14.26.3mf, Main housing 6.14.26.3mf, bottom chassis 6.14.26.3mf]
2026-06-21 added new bottom chassis
    made more space for battery and removed a part of the bulk in the middle of the chassis
    [bottom chassis 6.21.26.stl]
2026-06-21 Add Nano tape and 3D prints to the pricing
2026-06-23 added new chassis print
    [chassis and camera stand 6.23.26.3mf]
2026-06-28 Add Screw Set to the pricing table
2026-06-28 added to the readme
    Added sections for Arduino Housing and versions in README.
2026-06-28 Enhance README with version details and images
    Updated README.md to include detailed descriptions and images for versions 1.2 and 1.3 of the Arduino housing.
2026-08-09 added a power section the the markdown file
    Added Power section with budget, battery specs, and consumption calculations.
2026-08-09 Changing the table on contents from using the HTML Anchors to Native Markdown
    HTML Anchors are overly coomplicated and require everything to be lowercase, this can become confusing so I just switched everything to the use the build in headers which should work
2026-08-09 Create README.md for schematic folder
    Added a README file for the schematic folder.
2026-08-09 Added the schematic without LiDAR connected
2026-08-09 Enhance README with detailed schematic and subsystem info
    Expanded the README to include detailed sections on subsystems, electronics, and wiring, including power distribution, microcontroller details, actuators, and sensors.
2026-08-09 Renamed the schematic folder to electrical for further additions
2026-08-09 Revise README for Electrical folder
    Updated the README to reflect the correct folder name and provide additional context on the circuit and electronic choices.
2026-08-09 Fix link case sensitivity in README.md
2026-08-09 Updated ObstacleCode.py (added recovery code after pillar avoidance)
    [ObstacleCode.py]
2026-08-09 Modify Raspberry Pi 5 entry with additions and price
    Updated Raspberry Pi 5 entry to include additional components and adjusted total price.
2026-08-09 updated camera information in the cost report
2026-08-22 Finished up the "The robot" section for the github
    Added sections for Overview, Drive Configuration, Steering Configuration, Main Components, Sensors, Computer/Controller, Battery, and How It Works. Updated table of contents and reorganized content f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
2026-08-23 Fixed a mistake where the electrical systems flow diagram included a bunch of stuff following it
    added a "```" after the diagram
2026-08-23 Update schematic image in README
2026-08-23 Fix image path in README for circuit schematic
2026-08-23 Updated circuit diagram image
    Made it so it uses the correct new path instead of the old one
2026-08-23 Correct maximum steering angle to 45°
    Updated the maximum steering angle to 45° in the specifications.
2026-08-23 Change steering type and mechanism description
    Updated the steering type and mechanism from 'Rack & Pinion' to 'Ball joint' in the README.
2026-08-23 Finished the tables for chassis and robogt specifications
2026-08-23 Update ground clearance from 4mm to 3mm
2026-08-25 Fix link heading for Electrical & Sensor System
    Corrected the heading link for the Electrical & Sensor System section.
2026-09-03 Remove photo placeholders from README
    Removed placeholder sections for drive train photo and steering diagram from README.
2026-09-16 resolved lidar read blocking the rest of the program
    [ObstacleCode.py]
2026-09-22 Add wheelbase section to README
    Added a section on wheelbase explaining its impact on agility and turning radius.
2026-09-22 forgot to revert settings for full run (had the lap_direction manually set, and also made the code just run the parallel parking cide before)
    [ObstacleCode.py]
2026-09-29 the revertion of code during day 3 of us oc
    [ObstacleCode.py]
